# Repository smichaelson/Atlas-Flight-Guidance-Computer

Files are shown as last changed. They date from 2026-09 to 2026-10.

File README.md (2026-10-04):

# Atlas Flight Guidance Computer

Atlas is a collaborative STM32H743 flight-computer development project for the Rev. 0.1 board. It provides sensor and communications drivers, a statically allocated FreeRTOS framework, owned peripheral services, build projects, and reviewed hardware exports.

**Current status: diagnostic firmware 1.3.0; hardware qualification ongoing.** ServoBench now includes [four-servo gravity stabilization](docs/STABILIZATION.md) for a fixed bench demonstration, with a dashboard tab, SD-saved calibration/enable setting and SW2 control independent of USB. Read the [three-pass review](docs/STABILIZATION_REVIEW.md) for evidence and remaining physical checks. Manual single-servo workbench operation retains its direct moves, corrected PCB numbering, ADC averaging and 8.55 V cutoff. The rev-0.1 RGB and pyro inhibits remain mandatory. Passing builds and host models do not establish flight readiness.

## Start here

**Dashboard:** double-click **Start Atlas Dashboard.cmd** on Windows or [**Start Atlas Dashboard.command**](Start%20Atlas%20Dashboard.command) on macOS (Intel or Apple silicon). Install Python 3.10+ first; the launcher prepares its own environment and installs the bundled dashboard dependency offline. See the [Ground Station guide](docs/GROUND_STATION.md#start-the-dashboard) for setup, demo mode and Mac troubleshooting.

**USB updates and firmware builds:** see the [Ground Station guide](docs/GROUND_STATION.md). **Atlas Dashboard Demo.cmd**, **Build Atlas Firmware.cmd**, and **Build Atlas ServoBench.cmd** remain the Windows shortcuts. The latter builds the separate [manual servo profile](docs/SERVO_BENCH.md). Software DFU entry works after one initial installation. Firmware building/programming needs separate ST tools; they are not installed by the dashboard launcher. The [three-pass review](docs/GROUND_STATION_REVIEW.md) records the tested scope and physical checks still pending.

**PCB on the bench? Start with [startup](docs/startup.md)** — the complete power/BOOT0/reset/USB-programming procedure, local dashboard and staged tests. Build the **Bringup** preset, not the normal Debug/Release application. Check the documented USB schematic/manufacturing polarity conflict against the actual board before USB use.

For code collaboration, read [Quick start](docs/QUICK_START.md) and [Systems](docs/SYSTEMS.md): what runs, how to build/check it, and what remains unverified.

For implementation, use [Peripheral services](docs/PERIPHERALS.md) and [Development and engineering standards](docs/DEVELOPMENT.md). The [documentation hub](docs/README.md) indexes optional device, RTOS and hardware references. The [current review report](docs/REVIEW_REPORT.md) records corrections, three review passes, evidence and remaining release gates.

## Repository map

| Location | Purpose |
|---|---|
| [App](App/) | Drivers, RTOS ownership, typed snapshots, copied commands and safety policy |
| [Core](Core/), [FATFS](FATFS/), [USB_DEVICE](USB_DEVICE/) | Generated setup plus maintained board/filesystem/USB integration |
| [Tests](Tests/) | Protocol, integration, service-model and repository checks |
| [tools/bringup](tools/bringup/) | Offline-capable desktop dashboard, image verification and safe SD fixtures |
| [docs](docs/README.md) | Central documentation; references are optional, not a reading chain |
| [hardware](hardware/README.md) | Schematic PDF, BOM and candidate manufacturing exports |
| [ThirdParty](ThirdParty/), [Drivers](Drivers/), [Middlewares](Middlewares/) | Pinned dependencies; local USB patches are documented in provenance |
| [CMakeLists.txt](CMakeLists.txt), [EWARM](EWARM/) | Arm GNU and IAR project definitions |
| [Atlas.ioc](Atlas.ioc) | Generator inputs; runtime overrides and manual integrations must survive regeneration |

## Safety and provenance

All PWM, general GPIO and pyro outputs start disabled/low. The isolated **Bringup** image never enables PWM/pyro or calls the flight hook; it permits only explicit, one-second logic-GPIO tests and indicator/link/media actions. The separate **ServoBench** image permits one voltage-checked manual PWM channel with USB/time limits, or four explicitly configured stabilization channels gated by SW2 and sensor/power health. Stabilization can continue without USB; pyro remains inhibited. In the normal application, pyro arming and PWM operation require explicit qualified configuration; no flight decisions or remote firing parser are provided. The specified pyro policy is a 500 ms pulse, at least 500 ms OFF, and at most three retries: **four attempts per channel per boot**. Re-arming does not refill that budget.

Keep the physical pyro arm link open and disconnect energetic loads and servos during ordinary development. J5's armed feed bypasses the main eFuse. Use current-limited bench power; USB does not power the system rails. Output-low is an electrical state, not a guaranteed safe mechanical servo position.

No project-level license has been selected; vendor licenses remain applicable. See [provenance](docs/reference/PROVENANCE.md).

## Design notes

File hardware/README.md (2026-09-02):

# Hardware Reference Package

This directory contains review and manufacturing exports for the Atlas Flight Computer Rev. 0.1. It does not contain the editable KiCad project.

For contributor-facing pins, power and known discrepancies, use the centralized [hardware reference](../docs/reference/HARDWARE.md). For firmware capability and acceptance, use [Systems](../docs/SYSTEMS.md); this directory is the artifact manifest, not another bring-up guide.

## Files

- `Atlas-schematic-rev-0.1.pdf` - ten-page KiCad schematic PDF export, title-block date 2026-03-19.
- `AtlasBOM.csv` - generic component BOM from the source hardware folder.
- `manufacturing/` - candidate Gerber, drill, JLCPCB BOM, and component-placement package.

## Authority and limitations

The assembled board and confirmed as-built order records override these exports. The schematic is the primary electrical reference in this repository, while the firmware pin labels and `.ioc` configuration are implementation artifacts.

The exact files used for the already manufactured board were not identified in the source folder. Do not reorder from `manufacturing/` without completing the checks in [`manufacturing/README.md`](manufacturing/README.md).

No `.kicad_sch`, `.kicad_pcb`, `.kicad_pro`, footprint library, or symbol library is included. Obtain the canonical editable project from its owner before changing the design. Do not reconstruct an authoritative board from Gerbers.

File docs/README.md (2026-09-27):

# Atlas documentation

- [Four-servo bench stabilization](STABILIZATION.md) and [three-pass review](STABILIZATION_REVIEW.md).
- [Acknowledged RFD900x bench connection](RADIO_LINK.md) and [three-pass review](RADIO_LINK_REVIEW.md).
- [Remote Atlas sensor telemetry](REMOTE_TELEMETRY.md) and [three-pass review](REMOTE_TELEMETRY_REVIEW.md).

## Choose the question, not a reading list

| I need to… | Read |
|---|---|
| Power up the new PCB, program over USB and run the dashboard/tests | **[startup](startup.md)** — one complete bench procedure |
| Use the new browser dashboard and later USB updates | [Ground Station](GROUND_STATION.md), with [three-pass evidence](GROUND_STATION_REVIEW.md) |
| Test one free KST X10 servo with measured supply margin | [Servo bench workbench](SERVO_BENCH.md) |
| Understand the project and run its first checks | [Quick start](QUICK_START.md) |
| Know whether a subsystem is usable and how to accept it | [Systems and readiness](SYSTEMS.md) |
| Use SD, USB, ADC, GPIO, PWM, pyro, expansion or commissioning APIs | [Peripheral services](PERIPHERALS.md) |
| Build, test, add code, or review a change | [Development and engineering standards](DEVELOPMENT.md) |
| Understand a reported defect or the latest review evidence | [Current review report](REVIEW_REPORT.md) |
| Work on task ownership, timing, snapshots, or watchdogs | [RTOS reference](reference/RTOS.md) |
| Trace connectors, rails, pin assignments, or hardware conflicts | [Hardware reference](reference/HARDWARE.md) |
| Check vendor versions, licenses, or import decisions | [Provenance](reference/PROVENANCE.md) |

New collaborators normally need only **Quick start + Systems**. Bench operators use **startup** as their single procedure. References below are for the device or layer you are changing, not prerequisites to reading the application code.

## Device references

| Motion and environment | Navigation and links | Feedback |
|---|---|---|
| [ADXL375 high-g accelerometer](reference/modules/ADXL375.md) | [NEO-M9N GNSS / GPS](reference/modules/GNSS.md) | [RGB LED — hardware inhibited](reference/modules/LED.md) |
| [LSM6DSV16B IMU](reference/modules/LSM6DSV16B.md) | [NINA-B112 BLE](reference/modules/BLE.md) | [Differential buzzer](reference/modules/BUZZER.md) |
| [MMC5983MA magnetometer](reference/modules/MMC5983MA.md) | [RFD900x radio — J9 “LoRa” label](reference/modules/RFD900X.md) | |
| [MS5611 barometer](reference/modules/MS5611.md) | | |
| [BNO085 sensor hub](reference/modules/BNO085.md) | | |

SD, USB, ADC, PWM, GPIO, pyro and expansion now have owned services. Their commands, data units, result lifetime and qualification rules are centralized in [Peripheral services](PERIPHERALS.md). [Systems](SYSTEMS.md) distinguishes implementation from physical acceptance.

## How these documents stay authoritative

- **Systems** owns current capability and acceptance status. The **review report** owns current finding IDs and review evidence.
- **startup** owns the staged bench procedure, BOOT/reset/USB programming, dashboard use, fixtures and diagnostic wire protocol. Do not duplicate those procedures in device guides.
- **Development** owns engineering standards and build/test commands. **Peripheral services** owns the new board-service API contracts; **RTOS** owns scheduling and cross-owner rules. Per-device guides own protocol details.
- **Hardware** summarizes the schematic but never overrides as-built measurements, exact-part specifications, or unresolved discrepancies.
- [Earlier reviews](archive/REVIEW_HISTORY.md) are historical evidence only. Their “pass” conclusions and pre-correction failures do not supersede the current report.

This layout replaces the scattered status, validation, bring-up, building, architecture, standards, and review-index entry points. Relevant detail is retained in the references and a single historical archive; new reviews should update the current report rather than create another mandatory reading chain.

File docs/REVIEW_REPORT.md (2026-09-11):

# Atlas software review record

**Current correction:** [ServoBench 1.2.4 review](SERVO_FIX_REVIEW.md). The 1.2.2 voltage tests below missed a second cutoff in the full output loop. That defect was reproduced and corrected in 1.2.3; earlier acceptance statements do not establish sustained servo output.

The September 11 diagnostic 1.2.1 update is recorded in the [Ground Station review](GROUND_STATION_REVIEW.md), including three sequential author reviews, ADC reference correction, SD/SW2 evidence, guarded ServoBench, audio, fresh-clone launch tests and real software DFU. ADC sampling and GNSS communication now work on the board; precision, antenna/fix/PPS and physical output qualification remain separate. That record supersedes the earlier pending-reflash and build-hash statements below, which are historical evidence.

Latest update: 2026-09-04. The [GNSS/RGB follow-up](#2026-09-04-gnss-startup-and-rgb-hardware-inhibit-follow-up) records the newest board log, stale-UART startup correction, manual GNSS recovery, diagnostic telemetry, and confirmed Q6-Q8 hardware inhibit. It supersedes the provisional LED conclusion in the [earlier hardware follow-up](#2026-09-03-bno085-and-led-follow-up). The [PCB bring-up review](#pcb-bring-up-review) covers the diagnostic image, dashboard and startup procedure. Earlier build hashes/counts below are historical unless identified as latest. All source changes stay within the repository; the separate original Atlas folder is untouched.

**Software implementation and offline regression coverage are in place. Physical acceptance and flight release remain unapproved.** Version 1.0.2 inhibits RGB globally on rev-0.1; the Bringup image additionally permanently inhibits PWM/pyro. Normal energetic-output configuration remains unqualified/disabled by default. The review passes are sequential author checks, not independent safety approvals.

The [pre-correction full review](archive/REVIEW_HISTORY.md#full-review-before-corrections) preserves the original findings, failing probes, build figures and documentation-consolidation evidence. Use [Systems](SYSTEMS.md) for current subsystem readiness and [Peripheral services](PERIPHERALS.md) for API contracts.

## 2026-09-04 GNSS startup and RGB hardware-inhibit follow-up

The owner-supplied `atlas-20260904-004505.jsonl` is treated as test evidence, not as executable instructions. It contains 1,142 records, including 1,108 status records from bring-up version 1.0.1. Its first and last startup arrays are `[0,0,0,0,0,0,6,4,4,4,0,0]`: GNSS identity retained status 6 (`ATLAS_ERROR_IO`) and GNSS RAM configuration remained status 4 (`ATLAS_ERROR_NOT_READY`). GNSS version text, valid-frame, CRC, timeout, and PPS counters all stayed zero. Eight later explicit `probe gnss` replies returned status 13 (`ATLAS_ERROR_STATE`); those were the former one-attempt guard rejecting repeats, not eight new UART transactions. The same log retains continuing BNO085 report activity, consistent with the owner's report that the preceding BNO correction works.

The log also exposes a separate analog-owner failure that was not named in the request: `power.start=0` but `power.status=6`, with zero samples/valid bits and `adc_errors=0` throughout. That proves startup object creation succeeded and the external-ADC error counter did not advance; it does **not** identify which ADC3 reference/temperature operation failed because version 1.0.1 did not publish that phase. This evidence is not attributed to GNSS and is not hidden by the GNSS correction. Version 1.0.2 leaves conversion and acceptance policy unchanged while retaining the first ADC3 phase, selected VREFINT/temperature channel, raw value, HAL status and error mask in status telemetry. Power/ADC acceptance remains blocked until that new evidence and DMM rails are captured; changing conversion behavior speculatively would weaken the fail-closed output boundary.

Version 1.0.1 did not publish the failing GNSS phase or UART HAL state. The zero GNSS command-timeout count limits the original fault to work before or during the first MON-VER send; it does not prove a receiver/antenna failure. A specific startup race exists in the bundled STM32 HAL: NEO-M9N normally emits NMEA at 38400 baud before a staged probe, and `HAL_UARTEx_ReceiveToIdle_IT()` can return `HAL_ERROR` when an already-pending overrun aborts reception while it is being armed. The previous Atlas transport armed RX without first clearing stale hardware state. A timer/capture error before MON-VER also mapped to the same generic status, so the old log cannot distinguish those paths.

Version 1.0.2 corrects and exposes the boundary:

- UART start uses `HAL_UART_AbortReceive()` to disable stale receive state, clear hardware errors, flush RX, and restore READY before arming. One complete preflight/arm retry covers a receiver byte racing the short window; retries are bounded.
- GNSS sends only the read-only MON-VER identity poll every 250 ms inside one bounded 3 s startup window, so a command sent while the receiver protocol engine is still starting is not its sole opportunity to respond.
- GNSS proves checksum-valid MON-VER before it starts TIM2 channel-1 capture. A communication failure therefore leaves PPS unstarted and can be retried without clearing a live capture operation.
- A deliberate repeated GNSS probe first stops the failed transport. If identity had succeeded and only RAM configuration failed, it retries only configuration. Other modules and a fully successful GNSS remain single-shot.
- Health now retains stages 1–10, typed status, PPS-start state, RX/TX/drop/error/restart/preflight/retry counters, and HAL status/error. The dashboard renders them and the startup guide maps each stage to power/continuity/waveform checks.

The owner separately confirmed the actual LED design error from the raw KiCad source. DMN3404L Q6-Q8 are physically pin 1 gate, pin 2 source, pin 3 drain, while rev-0.1 routes intended load/control/ground to pads 1/2/3. Version 1.0.2 removes startup colors and dashboard on-controls, makes every nonzero direct/RTOS request unsupported, performs unconditional low writes, and requires `led_inhibited:true` plus zero-command status. The former “firmware mapping correct” conclusion is withdrawn.

### Three focused review passes

| Pass | Review performed | Result |
|---|---|---|
| 1 — evidence and hardware/driver contract | Parsed the complete new log; separated the single original I/O failure from rejected repeats; traced GNSS USART/PPS order, generated PB14/PB15/PA15 setup, U23 supply/SAFEBOOT/reset routing, bundled HAL receive-error behavior, official u-blox UART defaults, and official DMN3404L terminals | Failure is localized to a pre-MON-VER path but not falsely attributed from missing v1.0.1 telemetry; the real stale-RX race and confirmed Q6-Q8 mismatch have explicit dispositions |
| 2 — implementation and adverse paths | Added forced-low RGB tests, parser/UI/handshake denial, stale pre-probe UART injection, post-preflight arm-race injection, typed GNSS phases, a modeled 12-poll/3 s no-response bound, failed-identity/manual-retry coverage, shared-TIM2 regression coverage, and retained first-failure ADC3 telemetry tests | Host, service, bring-up and focused review suites pass; nonzero RGB requests cannot write high in the driver model; failed GNSS identity does not start PPS and a quiesced retry succeeds; ADC3 diagnostics do not alter conversion policy |
| 3 — target, documentation and final-diff review | Rebuilt both profiles/configurations, verified manifests/vectors/hashes, reran target diagnostics and all offline suites, checked documentation links/API tags, searched for LED-high paths, and reviewed the complete diff | See [latest executable evidence](#latest-executable-evidence). Physical GNSS communication and low-pin measurements remain required after flashing 1.0.2 |

These passes validate source behavior against controlled models. They do not prove that the assembled receiver has power, correct UART waveforms, a working antenna/fix, or valid PPS. Do not interpret manual retry as permission for an unbounded loop; preserve diagnostics and correct the physical cause first.

## 2026-09-03 BNO085 and LED follow-up

The first owner-supplied board log showed the other four sensor paths sampling while BNO identity returned `ATLAS_ERROR_IO`, its report setup remained `ATLAS_ERROR_NOT_READY`, and every BNO count/timestamp stayed zero. U12 SA0/H_MOSI is grounded, so firmware now uses seven-bit `0x4A` and passes left-shifted `0x94` to the STM32 HAL. The prior `0x4B`/`0x96` value contradicted the manufactured board contract.

The follow-up `atlas-20260903-230631.jsonl` still contains no accepted BNO report, despite the operator observing one transient value before or outside the retained status sequence. It shows a stronger shared-bus signature: MS5611 stopped after eight valid samples and then accumulated I/O errors immediately after the BNO probe, whereas the wrong-address run had left it sampling. Review found that the adapter performed the four-byte header and full read inside one callback while a payload-ready EXTI edge could remain latched as a new packet. The resulting no-data poll can clock-stretch BNO085 and strand I2C1. Version 1.0.1 now follows CEVA's separate header/next-interrupt/full-continuation state machine, uses transfer-length-aware bounds, and requires a genuinely new falling edge or confirmed H_INTN HIGH-to-LOW cycle before every subsequent read phase. A terminal BNO transfer failure holds U12 reset and restores I2C1 plus both generated filters before leaving the BNO disabled. The vendored product-ID operation also has a retained five-second timeout instead of its upstream unbounded wait.

At this earlier checkpoint, the D5 orientation evidence and package-pad measurements led to a provisional conclusion that the three low-side stages were routed correctly, so version 1.0.1 added PB6/PB7/PD14 readback. The subsequent raw-KiCad inspection established that conclusion was wrong: Q6-Q8's PCB pad functions do not match the fitted DMN3404L terminal assignment. The 2026-09-04 section supersedes this interpretation and disables all three outputs.

### Three focused follow-up reviews

| Pass | Review performed | Result |
|---|---|---|
| 1 — failure reconstruction and unit boundaries | Re-parsed both logs; mapped direct-sensor counter 3 to MS5611; traced shared I2C1, H_INTN ISR timing, CEVA SHTP assembly and reference I2C HAL; rechecked D5/Q6/Q7/Q8 and generated TIM4/GPIO ownership | Reproduced the stale-edge/no-data-read mechanism; separated LED package-pad measurements from MCU gate evidence |
| 2 — implementation and adverse cases | Added a virtual BNO that enforces header/held-LOW/idle/continuation/held-LOW/idle at the 1,024-byte CEVA maximum, wrong-extra-read detection, write/address bounds, injected terminal timeout and complete shared-bus restoration; added LED stuck-gate readback injection and actual C JSON/dashboard decoding | Host and bring-up suites pass; a full driver test uses actual CEVA SH-2/SHTP for reset, four product IDs and four feature writes; a separate silent-response test returns bounded `SH2_ERR_TIMEOUT` |
| 3 — target, operator and preservation review | Clean target builds, image manifest/vector/hash verification, all offline suites, target diagnostics, documentation/link checks and final diff review | See [latest executable evidence](#latest-executable-evidence); later board evidence confirms BNO streaming, while RGB illumination testing is withdrawn because of the hardware defect |

These are sequential author reviews, not independent hardware/safety reviews. Later owner evidence reports sustained BNO communication; calibration, timing, error-free soak, and shared-bus qualification remain open. RGB illumination is no longer an acceptance step on rev-0.1.

## PCB bring-up review

The operator's single procedure is **[startup](startup.md)**. The diagnostic scheduler is deliberately separate from the normal application: no control hook, actuator configuration, PWM enable or pyro arming/firing. ADC/input/USB services start immediately; sensor/link probes and SD mounting/testing require explicit commands. Component absence is visible without invoking the normal flight sensor-freshness reset loop. GPIO tests are bounded logic-only requests, not actuator tests.

### Three additional review passes

| Pass | Review performed | Result |
|---|---|---|
| 1 — hardware and functional contracts | Traced boot/power/USB/connectors against schematic and manufacturing pad attributes; reviewed staged ownership, output denial, command allowlist, measurement units and removable-media behavior | Complete. Recorded the USB polarity/protection conflict and provisional power gates; corrected result-backpressure and reconnect/identification handling |
| 2 — implementation and adverse cases | Built both profiles in Debug/Release, inspected symbols/memory, ran target compiler analysis and injected protocol, output and storage failures | Complete. Tests cover duplicate IDs, loss/overflow, old sessions, blocked/stale clients, GPIO expiry/disconnect, exclusive SD create/readback and failures; first diagnostic watchdog fault is retained |
| 3 — operator walkthrough and preservation | Read the complete startup path against code/pins; cross-checked exact payloads, artifacts and dashboard labels; reran final builds/tests/analysis and compared the preserved checkout | Complete. Corrected 23-byte SD / 19-byte link fixture descriptions, fixed signed numeric edge/null display handling, and made UI disconnect recover even if serial close fails |

These are three separate, sequential **author** reviews, not three independent reviewers. No actual PCB, COM port, DFU session, RF peer, motor or energetic load was accessed by that software-only review; the 2026-09-03 follow-up above uses owner-supplied log and inspection evidence. The synthetic dashboard and modeled serial lifecycle do not establish Windows-driver/electrical interoperability.

### Latest executable evidence

Toolchain: Arm GNU 14.3.1, CMake 3.26.4, MinGW Makefiles/GNU Make, host GCC 13.1.0, Windows PowerShell 5.1 / PowerShell 7 and Python 3.12.13/Tk. The extension's `cube-cmake` environment and Ninja were not used for the successful builds; [startup](startup.md#build-the-correct-image) includes the tested Makefiles fallback. No IAR build was performed.

| Check | Final result | Evidence boundary |
|---|---|---|
| Four clean target builds | Pass, no compiler warnings | Complete diagnostic and normal linked GNU images; matrix below |
| Strict target compiler/analyzer | Full 40-unit/profile pass on 2026-09-02; the eight current board/bring-up/protocol/GNSS/IO/LED/RTOS/UART units rerun in both profiles and pass on 2026-09-04 | Real Arm objects compiled with `-O0 -Wall -Wextra -Werror -Wshadow -Wformat=2 -Wdouble-promotion -fanalyzer`; not syntax-only |
| Existing host, focused-review and service suites | Pass | Includes real GNSS/SD/FatFs/USB paths and inert output policy/adapter models; no physical timing claim |
| [Bring-up suite](../Tests/bringup/run_bringup_tests.ps1) | Pass | Four C test executables, **14 Python tests**, actual C console JSON decoded by the desktop code, and a hidden 14-row Tk smoke test |
| Framing/formatting | Pass | 100,000 deterministic fuzz bytes, overflow/loss recovery, finite allowlist, signed boundaries/nonfinite values, escaped identities and bounded output |
| Desktop lifecycle and artifacts | Pass | Inert open-with-DTR-low ordering, no automatic TX/retry, partial-write uncertainty, failed-close recovery, stale/reset handling, SD fixture preservation and wrong-image/vector/hash rejection |
| Repository/documentation checks | Pass | Required files, local links/heading anchors, App Doxygen tags, static-memory/build membership and artifact policy; the checker uses explicit UTF-8 and a PowerShell-5.1-compatible relative-path implementation; see reproducible commands in startup |
| Linked profile boundary | Pass | Diagnostic entry present; normal scheduler/control hook absent; `AtlasRtos_OutputsPermitted()` returns zero; tested command boundary separately denies PWM/pyro/configuration |

The compiler audit suppresses only the intentional infinite-loop diagnostic in `main.c` and `stm32h7xx_it.c`, after inspection of their fatal inhibit paths, as in the preceding audit. No other analyzer warning is waived. Tests using inert register/serial/filesystem boundaries state those limits in their sources; they are not complete kernel/device simulations.

| Configuration | FLASH bytes | DTCM bytes | AXI DMA bytes |
|---|---:|---:|---:|
| Bringup / Debug | 210856 | 121912 | 64 |
| BringupRelease / Release | 110512 | 121816 | 64 |
| Normal Debug | 204556 | 89984 | 64 |
| Normal Release | 105524 | 89960 | 64 |

DTCM totals include the 16 KiB main-stack reservation. Diagnostic `_ebss` is `0x20019C38` in Debug and `0x20019BD8` in Release: only **8904 / 9000 bytes** remain before the MPU guard at `0x2001BF00`. This is not space available for unreviewed new buffers. Main stack remains `0x2001C000`–`0x20020000`; both 32-byte DMA blocks remain in AXI SRAM. Every image has one strong SVC/PendSV/SysTick/ADC/DMA1-stream-0/1/OTG-FS handler and no linked allocator/printf entry points. Stack-frame inspection and high-water telemetry do not replace full call-chain/FPU/interrupt and physical load testing.

Both diagnostic HEX/BIN/ELF manifests pass the actual offline verifier, including target/profile, hashes, initial SP/reset vectors, checksummed HEX and bank-1 boundaries. Exact final HEX SHA-256 values from this checkout:

```text
Bringup Debug   16c50f232972c21aff416392d11492748bec53b9c84f898855223e06bcde421f
Bringup Release bec2d82dfc9514cbe3b5d4006677d43cc0616a624e259b04050184db9fd8aeef
```

Build artifacts are retained only in ignored `build/` trees. Rebuild from your checkout, verify its generated manifest, and retain that image's evidence; source paths/compiler differences can alter the binary/hash. This is an accidental-wrong-image/corruption check, not signed firmware authentication.

### Physical gates and preservation

Two hardware findings remain explicit. First, the PDF's J2/U16 USB data connections conflict with the expected exported copper pad assignments; neither source proves the assembled board. Perform the [unpowered D+→PA12 / D−→PA11 check](startup.md#usb-data-polarity-is-a-required-as-built-check) and review U16's VBUS support-pin wiring before USB commissioning. Second, the owner-confirmed Q6-Q8 terminal mismatch makes the rev-0.1 RGB stage unusable; firmware inhibits it rather than concealing or compensating for it. No PCB/netlist/manufacturing file was changed. The eFuse input threshold, provisional current limits, crystal/boot options and actual rail/temperature/ripple behavior also require the explicit physical gates in startup.

No result here verifies sensor calibration/axes, SD-card durability, GNSS navigation/PPS quality, BLE SPS peer compatibility or RF range. The diagnostic image intentionally cannot qualify active PWM/pyro operation; their separate inert acceptance plan and approved normal configuration remain required. No software claim replaces disconnection of those loads.

The original bring-up preservation audit against the pre-bring-up ZIP retained all 374 existing repository files, with 348 byte-identical and 26 intentionally changed; 18 files were added. Vendor sources were byte-identical at that checkpoint. This follow-up intentionally changes only CEVA `sh2.c` in the vendor set to bound product-ID discovery; the exact patch and test are recorded in [Provenance](reference/PROVENANCE.md#local-integration-changes-2026-09-02-through-2026-09-04). All **19 manufacturing SHA-256 entries** still pass. No existing file was deleted, nothing was staged/committed, and the original Atlas folder was not touched. Generated Python caches and ignored build artifacts are excluded from source-file counts.

The complete pre-bring-up checkout, including existing dirty changes and `.git`, remains recoverable from the external `atlas_before_bringup_20260902.zip`, SHA-256:

```text
FD14CEBA8B3E6E94268320B3FEC8F04E563771AFC37873D765ADCF831EA843ED
```

The remaining sections record the **preceding correction review** and its original measurements; the latest build matrix above supersedes its build figures for the present checkout.

## Scope and method

Review covers all project-owned App implementations/headers and changed startup, clocks, MSP/IRQ/fault adapters, SD/FatFs, USB core/class/PCD, GNU/IAR membership/linker integration, tests and current documentation. Vendor review is limited to relevant integration paths and preserved provenance—not a line-by-line certification or current vulnerability audit of every dependency.

The schematic's ten pages were inspected in the preceding review, with additional focused power/output/ADC/connector cross-checks during correction. No board, module, card, RF peer or energetic load was exercised. No flashing, RF transmission, persistent module commissioning, filesystem formatting or physical firing was performed.

Owner-confirmed requirements: RFD900x on J9; KST X10 V8.0 servos; nominal 500 ms pyro pulse; ongoing continuity dependent on physical J5 connection; explicit software arming; at most three retries; at least 500 ms OFF. The implementation conservatively caps **four attempts per channel per boot**, preserving the budget across disarm/rearm and manual requests.

## Three correction-review passes

| Pass | Scope | Status |
|---|---|---|
| 1 — functional and fault contracts | Startup/shared time, SD lifecycle, USB control/retention, output timer/DMA/ADC/queues, commissioning and expansion; focused positive/adverse model tests | Complete; corrected additional implicit SD remount, short USB control/status lifetime, output-OFF queue fencing and ECC duplicate-count issues |
| 2 — separate rerun by the author | Clean Debug/Release, strict target compiler/analyzer, map/stack/handler inspection, full suite reruns; cross-check newly centralized API documentation | Complete; also corrected IAR stack placement, missing GNU guard exclusion and unintended libc allocation paths |
| 3 — delivery and preservation | New-collaborator walkthrough, examples/links/checker negative controls, regression review, exact target-drift/preservation and final target reruns | Complete; published sources match staging, unchanged files are byte-identical, and actual-checkout builds/tests/analysis pass |

All three passes are separate sequential author reviews, **not reviews by other people**. Two qualified independent safety reviewers and inert physical acceptance remain release prerequisites under [Development](DEVELOPMENT.md#change-and-release-checklist).

## Finding disposition

“Corrected in software” means the identified code/ownership defect is addressed and relevant tests pass; it does not close its physical acceptance gate.

| ID | Disposition |
|---|---|
| [R01](#r01-gnss-startup-restarts-an-already-running-timer) | Corrected: idempotent shared TIM2 start preserves counter/capture |
| [R02](#r02-rtos-waits-do-not-guarantee-minimum-device-delays) | Corrected: minimum elapsed waits with phase/overflow/context handling |
| [R03](#r03-sd-lazy-initialization-uses-an-unconfigured-handle) | Corrected: full SDMMC configuration and explicit optional-media lifecycle |
| [R04](#r04-sd-read-completion-can-be-erased) | Removed by design: synchronous polling port has no SD DMA completion race |
| [R05](#r05-sd-timeouts-do-not-establish-buffer-release) | Corrected: no retained SD DMA ownership; bounded polling/reset and media-generation invalidation |
| [R06](#r06-default-memory-is-not-sdmmc1-or-dma1-accessible) | Corrected: CPU-only SD/USB; private AXI ADC/pyro DMA blocks in both linkers, ECC seeding |
| [R07](#r07-usb-is-not-a-complete-or-started-cdc-service) | Implemented/corrected: VBUS owner, CDC controls, retained RX/TX, reset/timeout handling and FIFO allocation |
| [R08](#r08-gnss-parser-has-no-truncated-frame-age-limit) | Corrected: bounded UBX frame/interbyte age and transport-loss resynchronization |
| [R09](#r09-hardware-labels-and-power-protection-claims) | Superseded/corrected: raw-design evidence confirms Q6-Q8 terminal mismatch; RGB is firmware-inhibited pending hardware revision |
| [R10](#r10-deadline-checks-do-not-cover-release-lateness) | Corrected deadline coverage, priorities and fault gates; physical schedulability remains unverified |
| [R11](#r11-configured-peripherals-are-not-complete-services) | Added owned storage/RTC, USB, ADC/GPIO/PWM/pyro, expansion and commissioning APIs; qualified output profile and physical acceptance still required |
| [R12](#r12-bno085-address-disagrees-with-the-board-strap) | Corrected: SA0-low U12 now uses seven-bit `0x4A` / STM32 HAL `0x94`; post-reflash hardware proof remains required |

## R01: GNSS startup restarts an already-running timer

[AtlasTime_StartCounter](../App/Src/atlas_time.c) accepts only READY/stopped or BUSY/running states. BNO085 and GNSS both use it; a second client no longer calls HAL start again or resets the shared counter. A stopped BUSY handle still fails closed.

The real GNSS/UART probe models BNO's already-running timer, proves one HAL start, preserves the counter and proceeds to MON-VER/configuration. This is not a complete BNO/board startup simulation; actual BNO time, GNSS readback and PPS remain bench gates.

## R02: RTOS waits do not guarantee minimum device delays

[The helper](../App/Src/atlas_time.c) uses upward rounding plus one tick-phase allowance, overflow-safe chunks and explicit context rules. Pre-scheduler HAL waits are chunked; nonzero ISR/suspended-scheduler use asserts. The [timing tests](../Tests/review/test_timing.c) cover zero, maximum integer duration, earliest legal wake, pre-scheduler and context failures at modeled 100, 1000 and 2000 Hz.

At 1 kHz, the tested requested 3 ms wait has a modeled minimum of 3001 us, replacing the former 2001 us failure. This fixes the logical minimum-wait contract used by MS5611, MMC5983MA and BLE. Physical command timing and full-system 1 kHz scheduling still require measurement.

## R03: SD lazy initialization uses an unconfigured handle

[The BSP](../FATFS/Target/bsp_driver_sd.c) now prepares the complete SDMMC1 handle, initializes at one bit and negotiates four bits. Absent/failed media is optional, not a startup crash. [The storage owner](../App/Src/atlas_storage.c) owns mount/unmount/read/append and the [disk port](../FATFS/Target/sd_diskio.c) permits initialization only after explicit mount authorization.

## R04: SD read completion can be erased

The old callback/DMA read path is replaced by synchronous polling. There is no “launch then erase completion” flag. A private aligned sector buffer accommodates unaligned callers; no caller is retained asynchronously. The obsolete weak-callback host wrapper was retired, with its original preserved in the pre-correction backup.

## R05: SD timeouts do not establish buffer release

SD no longer uses IDMA. Errors reset/quiesce the controller, invalidate the mounted generation and reject old-session operations. Both mechanical detect edges count, including rapid remove/reinsert. The owner checks media before queued file work; disk status invalidates FatFs cached metadata and ST's disk-init cache. A file operation cannot silently remount a replacement card.

Transfer waits are 250 ms/sector and readiness waits 1000 ms with yielding; HAL internal commands/preemption can extend total wall time. A partial/failed append has an uncertain outcome and is never automatically retried.

[The real FatFs/BSP/disk RAM-volume test](../Tests/review/test_sd_integration.c) covers initialization, immediate polling completion, unaligned reads/writes, ranges, timeout/reset, ready waits, absence, replacement/removal, append preservation, cached-file rejection after replacement, and successful **explicit** remount. [The storage-owner test](../Tests/services/test_storage_owner.c) adds queue backpressure, removal-before-write, short append, failed sync and partial RTC updates.

## R06: Default memory is not SDMMC1 or DMA1 accessible

DTCM remains appropriate for CPU-owned data/stacks. SD uses CPU polling and USB PIO. ADC1 and TIM6's GPIO sequencer use two 32-byte private blocks in AXI SRAM `.atlas_dma`, explicitly placed by [GNU](../STM32H743XX_FLASH.ld) and [IAR](../EWARM/stm32h743xx_flash.icf). Complete 64-bit ECC words are initialized before subword DMA access.

[AtlasIo_Start](../App/Src/atlas_io.c) checks exact handles, buffer bounds, reviewed clocks, factory calibration and D-cache-off startup. Completion/abort must establish quiescence before reuse; failed buffers are quarantined. DMA1-to-GPIO D3 connectivity and memory/ECC assumptions were checked against the bundled HAL and [ST AN4891](https://www.st.com/resource/en/application_note/dm00306681.pdf)/[AN5342](https://www.st.com/resource/en/application_note/dm00623136-error-correction-code-ecc-management-for-internal-memories-protection-on-stm32h7-series-stmicroelectronics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). Actual DMA routing, cache policy, ECC behavior and pulse width remain inert bench requirements.

Pass 2 additionally found that IAR left CSTACK placement implicit despite the fixed MPU guard. It now explicitly places the 16 KiB main stack at 0x2001C000 and excludes guard/stack from ordinary data. GNU asserts the same stack base and rejects data reaching 0x2001BF00. A link-only negative control exceeds the guard boundary while still fitting ordinary DTCM capacity; it correctly fails the new guard assertion.

The generated C-library allocator also ignored the zero-heap reservation and could grow toward that guard. [The replacement boundary](../Core/Src/sysmem.c) rejects all heap changes with ENOMEM; [its host test](../Tests/services/test_sysmem.c) covers zero, positive, negative and extreme requests. Radio/BLE AT formatting now uses bounded integer/string construction, with shortest/longest name and zero/maximum integer wire checks. No allocator/printf path remains linked in the current GNU images.

## R07: USB is not a complete or started CDC service

[AtlasUsb](../App/Src/atlas_usb.c) provides VBUS debounce/recheck, prompt disconnect and task-owned teardown, a 1024-byte RX ring and four copied TX packets. Sessions invalidate stale data; a 2000 ms TX timeout tears down without replay. The CDC adapter validates line coding/control requests, retains TX memory until final data/ZLP completion and safely rejects pre-enumeration access.

Review also corrected malformed direction/interface/size handling, short control OUT payloads, failure-to-stall/incorrect status ACKs, stack-lifetime EP0 data, two-byte endpoint status, rejected TX launch and missing EP2 TX FIFO. The explicit local middleware changes are recorded in [Provenance](reference/PROVENANCE.md#local-integration-changes-2026-09-02-through-2026-09-04).

[The CDC test](../Tests/services/test_usb_cdc.c) compiles the real adapter plus ST core/class. [The owner test](../Tests/services/test_usb_owner.c) scripts initialization-time VBUS loss, unplug, overflow, result lifetime, timeout and re-enumeration without replay. Neither emulates electrical USB or substitutes for actual host/OS enumeration. There is a byte service, not a supplied console or trusted command protocol.

## R08: GNSS parser has no truncated-frame age limit

[The parser](../App/Src/atlas_gnss.c) rejects payload lengths above its 512-byte bound immediately, enforces 250 ms interbyte and 2000 ms whole-frame limits, and flushes/reset-resynchronizes after transport overflow/restart. Age is observed at service time; UART bytes do not carry individual wire timestamps.

Tests include clean/fragmented NAV-PVT, embedded sync bytes, invalid checksum, truncated in-range/oversized frames, elapsed-frame limit, clock wrap and transport loss. A valid packet after the formerly blocking header is parsed; discarded-length state is zero.

## R09: Hardware labels and power-protection claims

The owner confirmed RFD900x at the “LoRa” J9 connector. Documentation explicitly identifies J5's feed from VIN_RAW to PYRO_VBAT_ARMED as **bypassing TPS16850 U11**.

The D5 orientation can be correct while its three low-side stages are not. The owner's later raw-KiCad inspection confirmed that rev-0.1 routes intended LED load, MCU control, and ground to Q6-Q8 pads 1, 2, and 3, whereas the fitted DMN3404L uses those physical pins as gate, source, and drain. The earlier “active-high mapping is correct” conclusion is withdrawn. All three outputs are now forced low and nonzero commands are unsupported; no schematic or manufacturing output was altered to hide the defect.

## R10: Deadline checks do not cover release lateness

Control now outranks blocking sensor/link work. Scheduled release—not actual wake time—starts the 10 ms response budget, including snapshot wait and hook. Late work inhibits outputs, latches a fault and skips catch-up bursts. Non-maintenance sensor cycles at least 20 ms also fault. Slow conversions/commands/expansion do not stack in one cycle, and stream UART waits are capped at 10 ms.

A lock-free output gate expires at the earliest required sensor age; the output owner additionally requires fresh calibrated ADC and valid rails. Maintenance rejects armed/active outputs, serializes the hold against enable, and keeps control/actuation inhibited during the bounded operation and recovery.

Pure deadline/supervisor tests pass. No full-kernel scheduling simulation or physical WCET/jitter/stack-load evidence exists; those remain mandatory.

## R11: Configured peripherals are not complete services

Added services and their [central contracts](PERIPHERALS.md):

- Static SD/UTC owner with explicit removable-media lifecycle and append/read results.
- VBUS-aware USB byte transport and validated CDC adapter.
- Calibrated asynchronous ADC, raw inputs, allowed-mask GPIO and KST PWM service.
- Hardware-independent pyro policy plus separate timer/DMA adapter, continuous qualified continuity, software/physical-supply gates, four-attempt per-channel/boot cap and conservative OFF guard.
- Sole-owner raw UART4/I2C2/SPI3 expansion work.
- Queued radio identity/settings/parameter/host-baud and BLE SPS commissioning; no automatic persistence.

Safety review found and corrected OFF-command generation fencing and ECC duplicate-event accounting. The first ECC monitor/offset/type is retained; HAL's accumulated event code is consumed only after evidence capture.

The stock image does not claim qualified servo neutral/travel, pyro voltage/continuity thresholds, successful deployment, RF peer service, navigation suitability, application framing/authentication or flight algorithms. These are explicit remaining configuration/qualification work, not hidden automatic defaults.

## R12: BNO085 address disagrees with the board strap

The owner-supplied 2026-09-03 bring-up log recorded BNO identity as `ATLAS_ERROR_IO`, left all four report enables `ATLAS_ERROR_NOT_READY`, and contained no BNO samples. Other I2C1 traffic reached the MS5611, so the log did not support treating the shared bus as generally dead.

Manufacturing net attributes connect U12 pin 17, `SA0/H_MOSI`, to ground. The BNO085 data sheet selects seven-bit address `0x4A` when SA0 is low, but the driver used `0x4B` and therefore passed `0x96` to the STM32 HAL. The driver and current documentation now use `0x4A`, which becomes HAL value `0x94` after the required left shift.

The corrected-address follow-up still failed and also stopped the shared-bus MS5611 after eight samples. The two-phase read, edge-rearmed readiness gate, length-aware timeouts, bounded product-ID operation, reset-first shared-bus recovery and `bno.health` telemetry described above are now implemented and regression-tested. After reflashing, retain the ticketed `probe bno` reply, health object, product IDs, all four successful feature-report enables, advancing report counts/timestamps, continuing MS5611 samples, and a joint H_INTN/I2C logic-analyzer trace if the probe still fails.

## Executable evidence

The review uses Arm GNU 14.3.1 (Arm build 14.174), CMake 3.26.4, MinGW Makefiles/GNU Make, host GCC 13.1.0 and PowerShell 7. No IAR compiler or physical board is available.

| Check | Delivered-checkout result | Boundary |
|---|---|---|
| Fresh GNU Debug and Release builds | Pass; zero compiler warnings in both | Complete linked firmware; figures below |
| Strict target compile/static analysis | Pass on 37 translation units | 23 App files, 10 project adapters and 4 USB middleware files; `-O0 -Wall -Wextra -Werror -fanalyzer` |
| Host protocol suite | Pass | 15 test groups, including added BLE name and radio integer-format boundaries |
| Focused review probes | Pass, exit 0 | Real timing/GNSS/SD/FatFs and pure analog/pyro logic with injected boundaries |
| Service suite | Pass, exit 0 | Real output/USB/storage/expansion owners, real USB core/class and rejecting C-library heap boundary |
| Repository checker | Pass; 309 local links and 61 linked heading anchors | Doxygen, build membership, artifact/static-memory/stack contracts |
| Documentation examples and API references | Four C blocks compile against target headers; 136 named API references resolve | Three peripheral examples plus the application hook; not physical execution |
| Preservation | Pass | 276 untouched files byte-identical; 98 changed/new text files match reviewed staging; one backed-up wrapper retired |
| Physical/IAR acceptance | Not performed | No electrical, RF, flight, complete-kernel simulation or IAR-binary claim |

The analyzer initially reported the deliberate terminal loops in `Error_Handler` and the fatal exception handlers. Their preceding emergency-inhibit paths were inspected. Only `-Wanalyzer-infinite-loop` is disabled for `main.c` and `stm32h7xx_it.c` in this audit; all other diagnostics remain errors. Formatting scratch buffers are initialized, and the final audit has no unexplained diagnostics. The audit does not prove all paths correct.

Run the commands in [Quick start](QUICK_START.md#2-run-the-complementary-checks), including the added bring-up suite. The old expected-failure baseline is archived; every current behavioral assertion must pass. Do not weaken a fixture just to obtain green output.

### Delivered GNU build evidence

These fresh builds use the actual Desktop repository, not merely the staging copy. Build products and logs are retained outside the repository.

| Configuration | FLASH bytes | DTCM bytes | AXI DMA bytes |
|---|---:|---:|---:|
| Debug | 201616 | 89792 | 64 |
| Release | 104008 | 89768 | 64 |

DTCM figures include the linker's main-stack reservation. The main stack starts at 0x2001C000, ends at 0x20020000 and has its guard at 0x2001BF00. The two private DMA blocks are each 32-byte-aligned in the 64-byte AXI NOLOAD section starting at 0x24000000; their internal order differs between configurations and is not assumed by the code. Release disassembly confirms full-width `STRD` ECC-seeding stores.

Both images contain exactly one strong SVC, PendSV, SysTick, ADC, DMA1 stream 0/1 and OTG_FS handler. No libc allocator, heap-growth, printf or FreeRTOS allocator entry point is linked. A separate positive/negative link control proves the GNU guard assertion rejects a data allocation that still fits ordinary DTCM capacity but enters the guard.

The largest observed individual Debug stack frames are 1104 bytes for the storage task, 888 for the supervisor and 640 for the application task. These are **not** complete call-chain, FPU, interrupt, or runtime stack-margin proofs.

SHA-256 of these exact local build artifacts:

```text
Debug ELF   2C93712CD73EA007A37371ED92C130D8D4647A7BDF6C719D127227148513E0E0
Debug map   BAE5F3EE6C747E6468ED4E6D23E8A3AE81E5A355C43CDA6907012C57027258CC
Release ELF 341B9D2926FBE2EDC95A58CC802D85D4AE2A29C90ED33774486525DDE3A66EAB
Release map 3BE8DD9080875729621BED196FC54B744AA1E9715CADF2D08CC53B060C7E8721
```

Compiler diagnostics/debug metadata include source locations; relocating the source tree can change hashes and diagnostic-string footprint. Reproduce with the recorded toolchain and compare executable behavior/configuration, not an unrelated machine's hash alone.

### Documentation and delivery controls

The repository checker passed positive controls for compact Doxygen blocks, pointer-return functions, duplicate heading suffixes and ignored fenced examples. Seven negative controls were then correctly rejected: a missing visible file, missing heading anchor, missing parameter tag, missing pointer-return tag, new kernel FromISR call, libc formatted I/O, and an inconsistent IAR stack base. Restoring those controls returned the checker to a pass. Control fixtures were isolated outside the delivered repository.

The current navigation has two entry documents (Quick start and Systems), with one central peripheral guide and one engineering-standards guide. Device details remain optional references; the archive is explicitly historical. A fresh-reader pass checked startup versus runtime behavior, units/channel numbering, queue acceptance versus execution, persistence, failure handling, and qualification prerequisites.

Before publication, all 343 existing repository files matched the preserved snapshot: no concurrent target edits were overwritten. The correction changed 66 files, added 32 and retired only `Tests/review/sd_bsp_host.c`, leaving 374 delivered files excluding Git internals. All 276 files outside that change set remain byte-identical. All 19 manufacturing-manifest hashes pass. Changed/new text was compared with reviewed staging after newline normalization; raw hardware exports were not normalized or changed. `git diff --check` passes.

The pre-correction snapshot, including the retired wrapper, remains in the external backup `atlas_before_fixes_20260901.zip`, SHA-256:

```text
88513F2E979303E0A7E8C59A9C2581F23D2304B97360AC5EA41EAD2AC67FAB3A
```

Existing checkout changes were retained. No files were staged or committed, no branch was changed, and the separate original Atlas folder was not modified.

## Remaining release gates

1. Exact board/load electrical qualification, measured servo neutral/travel, arm-voltage/continuity thresholds, supply tolerances and inert timer/DMA cutoff evidence.
2. Actual sensor/GNSS/SD/USB/BLE/RFD900x communications and failure/recovery tests, including navigation quality and peer operation.
3. Measured scheduling, memory, ISR and stack margins under worst-case combined traffic and fault conditions; actual IAR build if used.
4. Approved Q6-Q8 PCB correction/rework and separate LED requalification; BNO085 long-run/calibration/shared-bus evidence; authorized USB product identity; application logging/framing/security and approved flight-state logic.
5. Qualified independent safety review and a responsible-owner release decision. Three author passes and green host tests do not satisfy that release approval.

No physical firing, actuator activation, RF transmission, board flashing, module nonvolatile configuration or original Atlas-folder edits were performed.

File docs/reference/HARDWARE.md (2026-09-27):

# Rev. 0.1 hardware reference

This guide summarizes the [ten-page schematic export](../../hardware/Atlas-schematic-rev-0.1.pdf) and the compiled [pin definitions](../../Core/Inc/main.h)/[MSP setup](../../Core/Src/stm32h7xx_hal_msp.c). It is not an as-built inspection, electrical certification or fabrication approval. Runtime capability and acceptance live in [Systems](../SYSTEMS.md).

## Authority and limits

The board uses STM32H743ZIT6 (2 MiB flash). The schematic title block is Rev. 0.1, dated 2026-03-19. Confirm the assembled revision and exact fitted parts before relying on a mapping. Device data-sheet axes are not automatically the board/body frame.

Current source assumes an 8 MHz HSE, 200 MHz CPU, 100 MHz HCLK, 50 MHz APB buses and 100 MHz timer kernels for the used timer configuration. PLL2 provides the 50 MHz SPI/USART/SDMMC/ADC kernel selections; PLL3 provides 16 MHz I2C and 48 MHz USB selections. These are source-derived nominal values, not measured clock accuracy.

Raw KiCad projects are intentionally absent. Obtain the canonical editable design from its owner for hardware changes. [Hardware package](../../hardware/README.md) and [candidate manufacturing manifest](../../hardware/manufacturing/README.md) retain their separate provenance.

## Power and physical inhibit

| Path | Intended role |
|---|---|
| J1 → `VIN_RAW` | Main power entry; polarity must be checked |
| `VIN_RAW` → U11 TPS16850 → `VIN_PROT` | Main protected input feeding regulators |
| `VIN_PROT` → MP8772 → `8V4_PWM` | Shared nominal 8.4 V actuator-header power |
| `VIN_PROT` → LM76003 → `5V_SYS` | Radio/header and other 5 V loads |
| `VIN_PROT` → LM76002 → `3V3_SYS` | MCU digital and 3.3 V loads |
| Ferrite-filtered `3V3_AUX` | Analog, GNSS/BLE and low-noise branch |
| **`VIN_RAW` → physical J5 arm link → `PYRO_VBAT_ARMED`** | **Bypasses U11; the main eFuse does not protect this pyro feed** |

The prior hardware overview's “shared input protection” claim for pyro current was incorrect and is withdrawn. No independent per-channel fuse/current limiter is shown in those paths. Keep J5 open and energetic loads disconnected during ordinary work.

The schematic states a 16.3 V maximum input and an undercharged four-cell source. Treat that as the present boundary until the owner supplies an approved input specification; a fully charged nominal 4S pack can exceed it. An overvoltage fault cutoff is not an operating allowance. No separate reverse-polarity stage is shown ahead of `VIN_RAW`; use current-limited bench power and confirm polarity.

J9 is directly on `5V_SYS`, not behind an accessory TPS2553 limiter. Budget radio transmit peaks and power integrity using the exact modem specification. Two 5 V and two 3.3 V accessory ports have TPS2553 limiters, but their enables are tied high and fault outputs are not monitored by this firmware. They are not software power cutoffs.

PWM headers share a live power rail with no individual electronic limiter per channel. Stopped PWM does not mean an unpowered actuator connector. USB VBUS is sensed, not used to supply the system rails.

The populated R32=133 kΩ / R33=13.7 kΩ divider with a typical 1.21 V TPS1685x UVLO threshold implies approximately 12.96 V rising input enable. A 12 V supply may therefore not start the board. Verify as-built values and limits; the staged 15 V current-limited procedure and meter points are in [startup](../startup.md#3-first-power--no-usb-no-card-no-external-loads), not an approved battery/load envelope.

## Boot and USB as-built gates

STM32 BOOT0 is TP8/U6 pin 138 (10 kΩ pull-down); NRST is TP13/U6 pin 25 (10 kΩ pull-up and capacitor). TP12 is **GNSS** SAFEBOOT, not STM32 BOOT0. J28 is a custom connector, not a standard Cortex-debug pinout. The complete [programming/pin procedure](../startup.md#2-unpowered-inspection-and-pin-map) includes the required ground/reference connections and power sequence.

**Newly identified discrepancy:** PDF page 5 connects J2's drawn D− side to the net named USB_D+ and D+ side to USB_D−. Manufacturing copper pad attributes instead identify J2 A6/B6 → U16 I/O1 → PA12 D+, and A7/B7 → U16 I/O2 → PA11 D−, the expected polarity. Attributes are not a continuity test or a certification of actual copper/assembly. Require the [unpowered USB continuity check](../startup.md#usb-data-polarity-is-a-required-as-built-check) before USB bring-up. Resolve any reversal in hardware; the USB PHY cannot swap pins in firmware. U16's unconnected-looking VBUS support pin also needs protection-circuit review. No hardware exports were changed to conceal either discrepancy.

## Sensor and communications connections

Addresses below are seven-bit I2C addresses; the HAL adapter applies the required address shift.

| Device/interface | MCU connection | Source-defined baseline |
|---|---|---|
| SPI2 bus | PB10 SCK, PC2_C MISO, PC3_C MOSI | Mode 3, prescaler 16, nominal 3.125 MHz; inspect actual signal integrity |
| ADXL375 U1 | SPI2; CS PG12; board MOSI gating | 400 Hz, 4-wire/right-justified |
| MMC5983MA U9 | SPI2; CS PG11 | On-demand conversion, 200 Hz bandwidth code |
| SPI3 bus / LSM6DSV16B U27 | PB3 SCK, PB4 MISO, PB2 MOSI; IMU CS PG10, INT1 PG2 | Mode 3, nominal 3.125 MHz; INT2 at TP11 |
| I2C1 bus | PB8 SCL, PB9 SDA | Shared BNO085/MS5611; external pull-ups |
| BNO085 U12 | I2C1 `0x4A`; reset PB13, active-low interrupt PG0 | SA0/H_MOSI is strapped low; four SH-2 reports; shares TIM2 timebase with GNSS |
| MS5611 U14 | I2C1 `0x77` | PROM/CRC, compensated D2/D1 conversion |
| NEO-M9N U23 | USART1 MCU TX PB14 / RX PB15; PPS PA15 TIM2 CH1 | 38400 8N1 host; stale-RX preflight before `MON-VER`; intended RAM-only 10 Hz NAV-PVT; external antenna J27; reset not MCU-routed |
| NINA-B112 U21 | USART6 MCU TX PG14 / RX PG9, RTS PG8 / CTS PG15 | 115200 8N1 RTS/CTS; reset PD4, SWITCH1 PG5, SWITCH2 PG4, module DSR driven PG6, DTR observed PE1 |
| RFD900x J9 | USART3 MCU TX PD8 / RX PB11; 5 V and ground | 57600 8N1 host; no routed radio hardware flow control |
| microSD | SDMMC1 D0–D3 PC8–PC11, CK PC12, CMD PD2; detect PD3 | One-bit initialization then four-bit / 25 MHz polling; PD3 active-low mechanical J3 detect |
| USB full-speed device | PA11 D−, PA12 D+; divider-sensed VBUS PA9 | VBUS-gated CDC owner; PIO, no USB DMA |
| External UART | UART4 MCU RX PD0 / TX PD1 | 115200 8N1 initially; explicit raw expansion service |
| External I2C | I2C2 SDA PF0 / SCL PF1 | Raw/register transaction service; attached-device contract required |
| External SPI | Shared SPI3; external CS **PG13** | Raw transaction service; mode 3 / nominal 3.125 MHz, serialized with the IMU |

J9's **RFD900x** assignment was explicitly confirmed by the owner on 2026-09-01. The schematic and generated `LORA_*` labels are legacy names. RFD900x uses its serial-modem/SiK interface, not a Semtech LoRa register protocol.

## Outputs and monitoring

| Group | Mapping / limitation |
|---|---|
| PWM1–4 | TIM1 CH1–4: PE9, PE11, PE13, PE14 |
| PWM5–8 | TIM3 CH1–4: PC6, PC7, PB0, PB1 |
| PWM setup | Runtime prescaler 99, period 3002: 1 MHz / 333.0003 Hz; disabled/GPIO-low until qualified enable |
| GPIO outputs 1–7 | PF2, PE4, PA5, PA7, PC5, PF14, PF13; initialized low |
| GPIO inputs 1–7 | PE2, PE3, PG1, PE7, PE8, PE10, PE15; raw input snapshot; application polarity/debounce/semantics remain explicit |
| External switch | PF12 raw input snapshot; no automatic arming/flight meaning |
| Pyro gates 1–5 | PD9–PD13; disarmed/low; qualified TIM6 + DMA1 Stream1 two-edge pulse service |
| Buzzer | PE5 TIM15 CH1 / PE6 CH2; runtime PWM1/PWM2 opposite phase; stopped initially |

TIM15's nominal 4.8 kHz request rounds to 208 counter counts (about 4807.7 Hz). Measure both terminals and their differential voltage. A scheduled beep stops only when I/O service reaches its expiry check.

| Analog source | ADC1 sequence / pin | Nominal conversion aid—not a threshold |
|---|---|---|
| `3V3_SYS` | Rank 1 / IN16 / PA0 | Divider ×2 |
| `8V4_PWM` | Rank 2 / IN10 / PC0 | Divider approximately ×3.105 |
| `5V_SYS` | Rank 3 / IN11 / PC1 | Divider ×2 |
| `VIN_PROT` | Rank 4 / IN2 / PF11 | Divider approximately ×9.133 |
| Armed bus | Rank 5 / IN17 / PA1 | 820 kΩ / 100 kΩ divider |
| Continuity 1–5 | Ranks 6–10 / PA2, PA3, PA4, PA6, PC4 | 470 kΩ feed, 100 kΩ return, 10 nF filtering |

The output owner calibrates both ADCs. ADC1 uses a completed-only ten-rank scan in AXI SRAM; ADC3 uses separate single-rank VREFINT and temperature conversions. Runtime overrides the generator's original ADC3 sequencing. The snapshot and bring-up status retain the first ADC3 operation/channel/raw/HAL failure independently from the external ADC1/DMA error count. Those diagnostics localize a software/hardware boundary but do not qualify reference accuracy. Divider ratios, reference/offset, settling, tolerances and safe diagnostic current require assembled-board validation. Do not derive firing permission from nominal divider arithmetic.

J5 has no independent digital contact sensor. The qualified armed-feed voltage is a supply-present proxy, not proof that a safe arm link/load is fitted. Continuity is UNKNOWN without that supply and during firing. The ADC equivalent drain multiplier is 5.7; the armed-supply multiplier is 9.2. Thresholds are application-supplied only after measurement; no qualified defaults exist.

## RGB LED hardware defect and mandatory inhibit

The board owner confirmed the D5 orientation, then identified the controlling defect in the raw KiCad design on 2026-09-04. The fitted Q6/Q7/Q8 type is DMN3404L-7, whose SOT-23 terminals are pin 1 gate, pin 2 source, and pin 3 drain. The PCB routing instead sends the intended LED load to transistor pad 1, MCU control through 220 Ω to pad 2, and ground to pad 3. Thus all three intended low-side stages have gate/source/drain assigned to the wrong physical terminals. D5 orientation or a software color swap cannot correct this.

| Legacy control / intended channel | Affected transistor path | Rev-0.1 result |
|---|---|---|
| PB6 `LED_R` / red | R106 → Q8 → R105/D5 | MCU drives pad 2/physical source; load reaches pad 1/physical gate; pad 3/physical drain is grounded |
| PB7 `LED_G` / green | R102 → Q7 → R101/D5 | Same terminal mismatch |
| PD14 `LED_B` / blue | R104 → Q6 → R103/D5 | Same terminal mismatch |
| `5V_SYS` / common anode | D5 supply | A correct anode supply does not repair the invalid switches |

Version 1.0.2 permanently treats PB6/PB7/PD14 as fail-dark outputs on this revision: initialization writes and verifies low, board startup has no color indications, nonzero requests are unsupported, and the updated dashboard requires explicit LED-inhibit telemetry. Do not drive these nets high or perform further illumination tests until approved hardware rework/a corrected PCB revision is electrically inspected and qualified. See the dedicated [RGB LED guide](modules/LED.md).

## Verification boundary

All schematic pages were visually checked for this review, including USB and the output/power paths. That did not validate PCB routing, manufacturing alignment, component substitutions, assembled wiring or electrical margins. [Systems acceptance gates](../SYSTEMS.md#acceptance-gates) and the [review report](../REVIEW_REPORT.md) retain those limitations.

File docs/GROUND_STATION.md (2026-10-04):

# Atlas Ground Station and USB updates

ServoBench **1.3.0** adds an autonomous [Stabilization tab](STABILIZATION.md): four radial servos, SD-saved settings and physical SW2 control. The single-channel USB/time limits below describe manual Servo workbench operation; stabilization has separate sensor, power and switch limits. See the [three-pass review](STABILIZATION_REVIEW.md).

Version 1.2.6 adds **Happy Birthday** beside Imperial March in Test controls. It plays once for 12 seconds, with the same Stop control and live playback status. Both diagnostic firmware profiles support it; older firmware keeps the new button disabled. See the [three-pass melody review](BIRTHDAY_REVIEW.md).

Version 1.2.5 applies each selected servo angle directly, using the servo’s own position controller. The dashboard offers angle buttons and numeric entry across nominal ±50°. It retains the corrected PCB PWM numbering (right 1 to left 8), 16-sample ADC averaging and 8.55 V output-loop cutoff. See the [servo review](SERVO_FIX_REVIEW.md). Version 1.2.2 added the owner-selected 8.55 V ServoBench cutoff and repairs the march transition. It retains the 1.2.1 work that corrects the ADC reference scaling, exposes SW2 and SD diagnostics, adds startup audio, and provides a separate ServoBench image for manual KST X10 tests. Atlas uses battery power; USB-C carries data. Follow the board inspection and power requirements in [startup](startup.md), including the 16.3 V input limit and mandatory RGB inhibit. Keep J5 open and pyro loads disconnected. Servos stay disconnected until the [servo bench procedure](SERVO_BENCH.md) is satisfied.

## Start the dashboard

Double-click **Start Atlas Dashboard.cmd** on Windows or [**Start Atlas Dashboard.command**](../Start%20Atlas%20Dashboard.command) on macOS, inside the complete repository folder. Both open [Atlas Ground Station](http://127.0.0.1:8765) in your default browser. Keep the launcher window running. **Atlas Dashboard Demo.cmd** opens explicitly simulated instruments and servo models with hardware actions disabled; the Mac launcher accepts `--demo` or you can choose **Explore demo** in the dashboard.

On a fresh Windows laptop, install Python 3.10 or newer with its Python launcher first. The Atlas launcher creates this clone's `.venv` and installs the bundled, SHA-256-verified pyserial wheel without network access. Do not copy another computer's `.venv`, browser shortcut, or absolute path. No Node packages, accounts, map service, or compiler are required for the dashboard. A failed setup leaves the error visible and details in `.atlas-launch.log`; an unusable environment is preserved under a timestamped name.

### macOS setup

1. Install a current Python 3 release (minimum 3.10) using the [official macOS installer](https://www.python.org/downloads/macos/). Its universal installer supports Intel and Apple silicon. Existing Homebrew Python installations also work; Homebrew is not required. Apple's `/usr/bin/python3` development-tools installation is deliberately skipped. See [Python's macOS guide](https://docs.python.org/3/using/mac.html).
2. Extract or clone the complete repository into a writable folder, then double-click **Start Atlas Dashboard.command**. It finds Python even with Finder's limited search path, creates `.venv/bin/python`, verifies and installs bundled pyserial 3.5, and launches the same dashboard as Windows. Python itself is a one-time prerequisite; Atlas's dependency setup needs no internet connection or administrator access. Tk is not required by this browser dashboard.
3. Keep Terminal open while using Atlas; press **Control-C** to stop the server. If the browser does not open, use the local address printed in Terminal. Select Atlas's `/dev/cu.usbmodem...` USB device in the dashboard; the exact suffix varies.

If a ZIP/extraction tool loses the executable permission, open Terminal in the repository folder and run:

```sh
chmod +x "Start Atlas Dashboard.command"
./"Start Atlas Dashboard.command"
```

From that folder, these optional commands check setup, start a demo, or choose another port:

```sh
/bin/bash "Start Atlas Dashboard.command" --check
/bin/bash "Start Atlas Dashboard.command" --demo
/bin/bash "Start Atlas Dashboard.command" --port 8766
```

`--check` prepares and verifies dependencies and prints the launch command; it does not open a server, browser, serial port or firmware operation. `--no-browser` starts the server and leaves browser opening to you. For a custom Python location, set `ATLAS_PYTHON` to its full executable path. Setup errors remain visible in Terminal; Python bootstrap errors also write `.atlas-launch.log` in the repository. An unusable environment is preserved and replaced; missing pip is repaired offline.

This launcher is for **macOS computers**, not iPhone/iPad. Firmware builds and USB DFU programming need their own tool installation and remain outside the Mac launcher verification. Native Finder/browser behavior and a physical Mac-to-Atlas USB connection have not been tested locally. See the [Mac launcher review](MACOS_LAUNCHER_REVIEW.md) for performed checks and the Mac CI coverage.

### Windows options and existing sessions

Launch paths are resolved from the launcher and Python source, regardless of the working directory. Repository documentation links are relative. `127.0.0.1` always refers to the computer running that copy of the dashboard; it does not connect to another laptop's server.

If the same clone already owns the port, the launcher opens its existing session. A different clone or older server on that port produces a clear message; close its launcher or run:

```powershell
& '.\Start Atlas Dashboard.cmd' --port 8766
```

For a setup/path check that does not open a server, browser, serial port or firmware operation:

```powershell
& '.\Start Atlas Dashboard.cmd' --check
& '.\Atlas Dashboard Demo.cmd' --check
```

The original [Tk dashboard](../tools/bringup/dashboard.py) remains available for ordinary Bringup diagnostics; the browser dashboard owns the ServoBench workflow.

## Connect and observe

1. Apply checked battery power and attach USB-C. Exit demo, choose **Connect device**, refresh ports, and select the STMicroelectronics Virtual COM Port. A COM number alone does not identify Atlas: the host validates the firmware profile, capabilities, UID and status frames.
2. **Overview** shows live attitude, histories, voltage, SW2 HIGH/LOW and SD detection/mount state. Switch LOW/HIGH describes PF12 electrically; no mechanical ON/OFF orientation is assumed.
3. **Start sensors** deliberately probes previously untested onboard sensors and GNSS once. BLE/radio and fixture tests are separate actions. An absent GNSS antenna means a valid navigation fix is not expected; an absent BLE module is not an installed sensor failure.
4. **Sensors** includes the ten ADC ranks and retained reference diagnostics. A healthy reference uses the H743's 16-bit factory and live values without the erroneous 12-bit conversion. Compare 3V3/PWM/5V/VIN against a meter; ADC readings are not a replacement for electrical qualification.
5. **Navigation** requires a valid fix for position and ground track. **Communications** shows USB, NINA BLE and RFD900x observations. J9's legacy “LoRa” label refers to a serial FHSS radio interface; RSSI, SNR and peer delivery are not fabricated.
6. **Test controls** contains explicit sensor, indicator, GPIO and media commands. **Servo workbench** contains the separate manual PWM procedure. RGB and pyro activation remain unavailable.
7. **Session log** records only after **Start recording**. Stop and export JSONL before closing the server. Records identify host UTC and live/demo source. The 12,000-record cap stops instead of overwriting old evidence.

Invalid or stale measurements are suppressed in instruments; retained observations are labelled. Histories hold 240 frames, about 120 seconds at 2 Hz. MCU status publication rate is not sensor sample rate. Model horn positions are commands/previews, never physical position feedback.

### If connection fails

Close an old server window before relaunching updated Python files; refreshing the browser alone does not replace the server. Select Atlas's USB COM device, not the PC's generic Communications Port. COM numbers can change between computers and after programming. ROM DFU has no application COM port.

The host opens with DTR low, waits 100 ms, clears old input, then raises DTR for a new handshake. This corrects the previous Windows startup race behind `Expecting value: line 1 column 1`. Missing handshakes time out clearly after eight seconds. Malformed telemetry still blocks hardware commands and retains an escaped, bounded rejected-record preview.

### SD card checks

Detection and mounting are separate. In **Test controls**, mount the card first, then read the prepared `ATLAS.TXT`. A missing read-test file is a filesystem error, not proof that the SD slot is broken. The dashboard displays named FatFs errors, controller failure stage, HAL status/error and detect-edge count.

The optional write/read comparison creates a 1,024-byte `ATLASCHK.TST` exclusively and checks its contents. It refuses to overwrite an existing file. It does not format the card. Unmount before removing media; power Atlas off before moving the card to a PC. Safely eject on the PC before returning it to Atlas. The September 11 card check mounted and read `ATLAS.TXT` successfully with the previous 1.1.1 firmware; no SD clock or bus-width change was needed for that result.

## Play the buzzer melody

Startup plays four rising notes once after the buzzer owner starts, even without a dashboard connection. This is a power-on sound, not a flight-readiness annunciation.

**Test controls → Indicators & logic → Imperial March** plays a single 42-note arrangement, 16.5 seconds. Version 1.2.2 restores the high-G repeat and short E–E♭–E turn in the bridge beginning at note 19, corrects the later B♭ landing, and places both opening phrases on four-second boundaries at 120 beats/minute. The closing phrase starts at 13.25 seconds with E♭–F♯–E♭–B♭ before returning to G; this is the owner's accepted Preview C. The owner's preferred lower octave is retained: 311–784 Hz, with a 300 Hz driver minimum. This remains an adaptation of the owner's supplied rough phrases. Timer reload and compares latch together before each tone starts. Firmware 1.1.1 reports its older 33-note/11.36-second sequence.

**Test controls → Indicators & logic → Happy Birthday** requires firmware 1.2.6 and plays the traditional 25-note tune once: C major, 120 beats/minute, 12 seconds, 392–784 Hz. The status names the active song and shows its note count. Both melody buttons are unavailable during playback or active servo PWM; another song is never queued.

**Stop indicators** cancels either melody. USB/DTR loss, a changed session, fault or a new sensor/link command cancels it; there is no replay queue. Polling continues while it plays and late service skips elapsed notes. Firmware update is refused during audio. Status shows MCU playback progress; actual pitch, loudness and differential waveform still require acoustic/scope acceptance.

## Build and first installation

| Root launcher | Output | Capability |
|---|---|---|
| **Build Atlas Firmware.cmd** | `build/BenchMake/Atlas-Bringup.hex` and matching manifest | Diagnostics with PWM/pyro inhibited |
| **Build Atlas ServoBench.cmd** | `build/ServoBenchMake/Atlas-ServoBench.hex` and matching manifest | Diagnostics plus explicitly gated, one-channel manual servo PWM; pyro inhibited |

Builders need the Arm GNU compiler, CMake and GNU Make in addition to Python. They discover installed tool locations and report missing tools; they do not program hardware. Both emit ELF/HEX/BIN/manifest and validate target, vectors, hash and image agreement. The CMake Bringup/ServoBench presets are also available when using Ninja. Normal Debug/Release firmware is not accepted by this dashboard updater.

The launchers use Python directly, so PowerShell script-execution policy does not need to change. On a clone with no build artifacts, the dashboard still opens and connects; build a profile before verifying a new image. Select an explicit manifest for a custom build folder. Relative manifest paths resolve inside this clone.

An image older than 1.1.0 needs **one initial BOOT0/NRST DFU or SWD installation**. Follow [initial programming](startup.md#4-program-the-stm32-over-usb-dfu), verify the exact image, and cold-cycle power. An old application cannot implement a new command until it is replaced.

## Later updates without BOOT0/NRST

With Bringup/ServoBench software-DFU support installed, BOOT0 remains LOW:

1. Stop PWM and indicators, finish commands, and unmount SD. Keep loads isolated and battery/USB stable.
2. Build the desired profile. In **Firmware**, select **Bringup** or **ServoBench**, then **Verify image**. This freezes a validated bank-1-only image. An explicit manifest takes precedence over the selected profile; review the displayed profile and hash.
3. Choose **Update Atlas** and review the concrete image. The serial owner rechecks identity and idle state, then sends one UID-bound bootloader request. Firmware waits for acknowledgement transfer completion and uses a one-shot marker/software reset to enter factory ROM before HAL/RTOS setup.
4. The host requires a single DFU target, pins every programmer command to its DFU serial, and compares physical UID/family with the application handshake before writing. A wrong or ambiguous target aborts.
5. CubeProgrammer downloads and verifies the bounded HEX. The updater performs no mass erase, option-byte change or readout-unprotect. A failed verify does not run or retry the image automatically.
6. ROM 0x91/0x92 permits the application-start request. Other or unreadable ROM versions require a cold power cycle, which the UI reports explicitly. Even a supported ROM may need a cold restart: if the flash verifies but the application COM port does not return, disconnect both USB-C and battery, leave BOOT0 LOW, then restore battery power and USB-C. Reconnect and verify the new profile/version and live data. Do not repeat a verified flash just because the restart did not complete.

The September 11 test verified software-requested programming of 1.2.1 on this board. One ROM 0x92 update returned directly; the latest required the cold restart above. Automatic return is not yet reliably qualified.

A broken application, interrupted update or USB driver problem can still require physical BOOT0/NRST or SWD recovery. Factory ROM owns its own pins during DFU; application output inhibits do not govern ROM. See the same isolation requirements as initial programming. Normal/flight builds have no maintenance command parser and remove the dashboard's update route.

## Engineering details and references

The wire command is `ID bootloader UID0 UID1 UID2`; `software_dfu:true` advertises support. UID matching prevents accidental wrong-device writes; it is not authentication. BLE/radio cannot send these commands. Entry cancels on an expired drain deadline, dropped acknowledgement, session loss or newly unsafe/busy state.

An 8-byte `.atlas_boot` marker in DTCM requires a complementary value and software-reset cause. Cold boots never read uninitialized marker memory. The initial MSP is `0x2001FFE0`, reserving the ROM Go restriction's top 32 bytes; the existing stack/MPU guard remain. GNU and IAR layouts agree, but actual IAR compilation is unverified.

The server binds to loopback, serves a fixed asset allowlist, checks Host/Origin, requires a random session token, and bounds requests/captures. Opening the page never opens a COM port. Optional WebMCP telemetry is read-only.

- ST [AN2606](https://www.st.com/resource/en/application_note/an2606-introduction-to-system-memory-boot-mode-on-stm32-mcus-stmicroelectronics.pdf), H74xxx/75xxx bootloader resources and ROM-version restrictions.
- ST [CubeProgrammer command reference](https://dev.st.com/stm32cube-docs/prog/2.23.0/en/docs/markup/CubeProg_Command_Lines.html), target selection, read, download/verify and Go.
- [Servo bench procedure](SERVO_BENCH.md) and [review record](GROUND_STATION_REVIEW.md), including limitations of host tests and actual bench evidence.

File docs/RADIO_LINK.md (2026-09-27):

# Atlas bench radio connection — 1.4.0

Firmware 1.5.0 retains this acknowledged diagnostic link and adds automatic
[remote sensor telemetry](REMOTE_TELEMETRY.md) in a separate dashboard tab. Pause that
broadcast on both boards before entering guarded AT diagnostics.

The dashboard's **Communications → RFD900x** panel now distinguishes local UART startup
from a verified round trip to another Atlas. Both boards need Bringup or ServoBench
1.4.0. USART3 in both the generated source and CubeMX project uses **57600, 8N1**, matching
the [RFDesign Point-to-Point/SiK factory setting](https://files.rfdesign.com.au/Files/documents/RFD900x%20Peer-to-peer%20V3.X%20User%20Manual%20V1.4.pdf).
The modem's solid green LED establishes RF synchronization; Atlas-level verification
also tests both board UARTs and the peer's application. No modem EEPROM or RF settings
are changed by this update.

## Operation

- Boot starts passive reception. A battery-only board can respond without opening its dashboard.
- **Connect & monitor** performs a test, then issues another every three seconds.
- **Test round trip** supersedes any pending background test and waits up to two seconds
  for a matching response. USB remains responsive; the sensor owner continues sampling.
- A successful test shows peer UID and round-trip milliseconds. A failed UART write and
  a missing peer reply are separate failures. The last explicit test result remains
  visible while monitoring runs.
- **Connected** requires a matching reply less than six seconds old. A failed subsequent
  test clears the connection immediately at its two-second deadline. USB/owner staleness
  suppresses the dashboard's connection claim even if the last stored frame was green.
- **Stop monitoring** clears local connection proof and stops originating tests. The
  board continues to answer valid peer tests. Monitoring is volatile, survives USB
  disconnect, and ends on board reset. It is independent of SW2 and stabilization.
- For local AT identity diagnostics, stop monitoring at both ends and allow the serial
  guard interval. AT access remains blocked while stabilization is enabled.

Both firmware profiles keep their existing output policy. RF traffic cannot enter the
USB console or issue any output, stabilization, storage, settings or bootloader command.
The new protocol carries diagnostic challenges and responses only. ServoBench's saved
calibration, reverse mask, SW2 gates, power checks, PWM timing and standalone operation
are unchanged. The normal application retains its existing radio byte API.

## Wire and timing contract

Each fixed 44-byte frame contains `ATLR`, version 1, type PING=1 or ACK=2, two reserved
zero bytes, sender UID (three uint32), destination UID (three uint32), uint32 sequence,
uint32 originating millisecond timestamp, and CRC-32/ISO-HDLC over the first 40 bytes.
Integers and CRC are little endian. A zero destination is valid for discovery PINGs only.
ACKs must address the full local UID, originate from a different nonzero UID, and match
the outstanding sequence and timestamp before the deadline. CRC provides corruption
detection, **not authentication**; this is not a secure remote-control protocol.

The 44-byte sliding parser handles arbitrary fragmentation/noise without dynamic memory.
Unknown types, versions, reserved bits, CRC failures, local echoes, stale/foreign ACKs
and arbitrary console text do not establish a connection. ACKs are never acknowledged.
There is one reply slot; surplus PINGs are dropped. Replies are limited to one per 100 ms.
Service sends at most one frame per call. A 44-byte UART transfer at 57600 takes about
7.64 ms, with a 20 ms HAL bound; the two-second peer wait is asynchronous. The independent
IO task retains its 5 ms control cadence and existing 100 ms IMU freshness limit.

`hello.radio_link=1` advertises the capability. Radio status includes actual host baud,
monitoring/connected/waiting, last peer/ACK age/RTT, sent/received/replied/acknowledged
counts, timeouts, UART errors/drops, corrupt frames, and a separate last-test sequence,
peer, RTT and result: 0 idle, 1 waiting, 2 acknowledged, 3 timeout, 4 transmit error,
5 cancelled. `ack_age_ms=UINT32_MAX` means no currently retained acknowledgement.

## Verification

Run `Tests/bringup/run_bringup_tests.ps1` for radio protocol, production USB completion,
Python schema/command gates and browser presentation tests, along with existing bench
regressions. Host/service tests and all four build profiles cover shared firmware changes.
See [the review and hardware record](RADIO_LINK_REVIEW.md) for this installation.

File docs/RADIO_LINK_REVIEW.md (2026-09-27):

# Radio link 1.4.0 review and installation record

Scope: two connected Atlas boards, factory RFD900x serial settings, bench communication
only. The user requested at least three reviews. These are focused review passes by
the implementing agent, not independent certification or RF/electrical qualification.

## Review 1 — protocol and evidence

Reviewed frame boundaries, ownership of UIDs/challenges, CRC validation, timeout boundaries,
tick wrap, duplicate/self/foreign replies, simultaneous tests and bounded response traffic.
Connection depends on a matching round trip, never UART-write success or inbound PING alone.
Expired proof is permanently cleared by service, preventing revival after a full tick wrap.
The parser has no command-dispatch path. Tests cover every split point, each damaged byte,
each truncated prefix, arbitrary command text, replay, late ACK, transmit error, peer loss,
monitoring, concurrent two-way tests and response flooding. Passed.

## Review 2 — integration and preservation

Reviewed sole UART ownership, the asynchronous USB completion and queue backpressure,
USB epoch fencing, IMU/service timing, stabilization gates, saved configuration and DFU.
The owner continues sensor work while waiting for RF. Only the three bounded radio
diagnostic operations are exempted from the stabilization maintenance block; local AT
and other maintenance remain blocked. Radio test results are published before USB
completion and cannot be replayed into a new USB session. Production console tests cover
waiting, timeout, successful peer detail, full result queue, disconnect and maintenance
denial. Existing servo, stabilization/persistence, buzzer, IO, USB, storage, expansion and
driver tests passed. A new console test initially assumed a zero storage counter after
earlier tests; corrected it to assert the counter is unchanged, then the suite passed.

## Review 3 — release, dashboard and hardware

Reviewed the final diff, generated USART3 configuration, CMake/IAR source membership,
capability/schema compatibility, dashboard freshness and result presentation, all four
build profiles, frozen image identity and physical target selection. Completed the
installation and hardware checks below on 2026-09-27. Passed.

This pass found two dashboard issues and corrected both: **Stop monitoring** needed the
existing HTTP deliberate-action flag, and historical timeout counts must not label an
intentionally stopped monitor as a current failure. Regression tests exercise both.
Actual dashboard Connect, Test, Stop and restart operations were checked against device
responses. The refreshed Communications page shows the responding peer and a successful
test while the peer runs on battery alone.

## Build and regression results

- Normal Debug, normal Release, Bringup and ServoBench builds passed. USART3 is 57600
  in both generated C and CubeMX; other UART configurations are unchanged.
- Bringup suite passed, including pure-C radio/parser and production console tests,
  nine new Python radio tests, browser presentation tests and existing dashboard,
  ground-station, servo, stabilization, persistence, boot, IO and storage regressions.
- Host driver and service suites passed, including actual USB class/owner, expansion,
  storage and IO implementations. Final radio UI regressions passed after the two
  display/control corrections.
- Repository documentation/source checks and whitespace checks passed.
- Installed ServoBench image uses 239848 bytes of flash and 123672 bytes of DTCM,
  leaving 7400 bytes within the 128 KiB DTCM region.

## Device inventory before installation

| USB port | MCU UID (decimal words) | Previous firmware | Saved stabilization |
|---|---|---|---|
| COM3 | 3342386 / 859001093 / 943273521 | ServoBench 1.3.4 | Enabled, calibrated, reverse mask 15, SD present |
| COM4 | 3407904 / 859001093 / 943273521 | ServoBench 1.2.5 | Not supported by old firmware; SD absent |

Both boards reported SW2 OFF, PWM off, pyro disarmed and SD unmounted before installation.
The owner also confirmed both SW2 switches OFF. COM3 calibration was preserved while
stabilization was temporarily saved OFF for the existing DFU interlock; its prior enabled
state was restored afterward and verified to reload after a later power cycle.

## Installation and hardware results

Both MCU UIDs were checked through the application and again through the ROM bootloader
before programming. Both flash writes verified against the same frozen ServoBench
1.4.0 image. Following the requested full power cycle, both applications enumerated and
reported version 1.4.0 with the radio-link capability. Startup was established by these
application observations, not merely by the programmer's start request.

Installed HEX SHA-256:

```text
7c7f2b85587fa0a2cb4d9fe5ca49a6c27e1c94b7549db6495a8f037d8c54ae88
```

| Check | Observed result |
|---|---|
| COM3-initiated tests | 10/10 acknowledged by COM4; 68–241 ms round trips |
| COM4-initiated tests | 10/10 acknowledged by COM3; 90–300 ms round trips |
| Healthy paired runs | No UART errors, receive drops, invalid frames, transmit failures or test timeouts |
| Sensor/task continuity during those runs | Maximum observed IMU age 10 ms on COM3 and 6 ms on COM4; no task faults or power events |
| Peer powered off | Explicit connect returned a 2000 ms timeout; dashboard showed no peer response and remained responsive |
| Peer restored, battery only | COM4 absent from Windows USB ports; automatic monitoring recovered, and explicit test 63 received its ACK in 75 ms |
| Dashboard Stop and restart | Stop cleared monitoring/connection proof; restart received peer ACK in 176 ms |
| COM3 saved stabilization | Enabled, calibrated, saved, reverse mask 15; preserved across the later power cycle |
| Output state | SW2 OFF, PWM off, pyro disarmed and logic outputs low throughout the radio checks |

COM3 also restarted during the peer-power-off exercise, so this run establishes timeout
and recovery behavior, not an exact measured connected-to-disconnected latency. The
continued monitoring during the deliberate outage accumulated 31 expected timeouts;
these remain historical counters after recovery, not current link failures.

Local evidence is retained under `build/radio-140-*`: preflash inventory, programmer
verification, per-board replies/telemetry, peer-off status, battery-peer recovery and
final dashboard state. Build/test logs use `build/radio-*-tests.log` and
`build/radio-*-build.log`; the final UI capture is `build/radio-dashboard-connected.png`.

Existing functionality was checked through the regression suites, source review and
preserved device settings. Outputs remained off; servo motion and pyro hardware were
not requalified during this radio installation. These are bench communication results,
not an RF range, electrical or general flight qualification.

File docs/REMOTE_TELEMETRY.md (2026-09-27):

# Remote Atlas telemetry — firmware 1.5.0

Both bench profiles now initialize onboard sensors and broadcast a complete read-only
snapshot about once per second. Connect either board by USB and open **Remote Atlas**.
Its peer needs battery power and a paired RFD900x, but no USB cable, dashboard, SW2 change
or remote command. Both boards require 1.5.0. The existing Communications round-trip test
remains available and has its own explicit acknowledgements.

The remote view includes direct accelerometers/gyroscope, magnetometer, barometer,
BNO085 reports/quaternion, GNSS position/fix/PPS, ten ADC channels with raw readings and
voltages, temperature, storage presence/errors, SW2, PWM/stabilization state and faults.
Missing sensors and an indoor GPS without a fix are reported as unavailable, not zeros
or invented positions. Local and remote measurements have separate envelopes and UI
state; remote data cannot set local outputs, answer local commands or refresh USB status.

Sensor startup runs once before stabilization IMU samples are published. Allow startup
to finish before using SW2. Existing saved calibration, switch interlocks, independent
5 ms IO task, 100 ms IMU stale limit and output policies remain in place. GNSS configuration
uses the existing volatile RAM setup; modem settings and SD contents are not changed.
An optional sensor failure does not stop other sensor reporting.

## Packet and redundancy contract

This is an application packet protocol above the modem byte transport, not a forwarded
serial terminal. Every snapshot is 512 bytes, divided into eight 64-byte data shards and
two 64-byte repair shards. Any eight of the ten checked shards recover the snapshot.
Each full 100-byte packet contains:

| Bytes | Field |
|---|---|
| 0–3 | `ATLT` magic |
| 4 / 5 | Packet version 1 / telemetry type 1 |
| 6 / 7 | Shard index 0–9 / data-shard count 8 |
| 8–19 | Source MCU UID, three little-endian uint32 words |
| 20–27 | Random 64-bit source boot identifier |
| 28–31 | uint32 snapshot sequence, wrapping naturally |
| 32–95 | 64 payload/repair bytes |
| 96–99 | CRC-32/ISO-HDLC over bytes 0–95 |

The snapshot has an additional CRC-32 over its first 508 bytes. The first repair shard
is the XOR of all data shards. The second is their weighted sum over GF(256), polynomial
`0x11d`, with coefficients `2^index`. Two missing or CRC-rejected shards can be repaired;
an incomplete or bad whole-snapshot CRC never updates displayed measurements.

The bounded sliding parser resynchronizes after byte loss, insertion, truncation or
noise. Assembly accepts reordered shards, rejects duplicate/older sequences and expires
after 1500 ms. One peer UID is retained for the gateway boot; a different board is counted
as a foreign sender. Peer reboot changes clear the old partial snapshot, while four recent
retired boot identifiers reject delayed packets. CRC/UIDs are integrity/identity checks,
not cryptographic authentication. This protocol contains no control messages.

Boot identifiers use the STM32H743 RNG with a total 20 ms initialization/read bound and
clock/seed error checks. A failure disables local broadcasting while reception remains
available. The temporary HSI48/RNG setup restores its clock selection and does not change
USB or sensor clocks. See ST [RM0433, RNG](https://www.st.com/resource/en/reference_manual/rm0433-stm32h742-stm32h743753-and-stm32h750-value-line-advanced-armbased-32bit-mcus-stmicroelectronics.pdf).

Packets are paced at least 35 ms apart; a complete batch is nominally 1000 UART bytes per
second per direction at 57600 8N1. One UART send is at most 100 bytes, bounded to 25 ms;
there is no peer-response wait, heap allocation, retransmission queue or old-data backlog.
Unfinished outgoing batches older than one second are abandoned in favor of a new snapshot.
Explicit ping/ACK work has priority over a telemetry send in that owner iteration.

## Snapshot schema

All values are little-endian 32-bit words. Signed measurements use two's complement;
`INT32_MIN` means an unavailable scaled measurement. Reserved words are zero. The stable
field offsets are in [atlas_telemetry.h](../App/Inc/atlas_telemetry.h); the laptop mapping is
in [remote_telemetry.py](../tools/bringup/remote_telemetry.py). No C structure padding is sent.

| Words | Contents |
|---|---|
| 0–4 | `TLS1` schema magic, source uptime, firmware version, profile, attempted sensor mask |
| 5–32 | Init results, successful sample counts, error counts, sample statuses and times |
| 33–47 | Direct acceleration in mg, gyro in millidegrees/s, temperature in centidegrees C, magnetic field in nT, pressure in Pa |
| 48–69 | BNO report counts/times/accuracy; acceleration mm/s², gyro milliradians/s, magnetic nT, quaternion W/X/Y/Z in millionths |
| 70–80 | GNSS receive time/count, fix/flags/satellites, lat/lon in 1e-7 degrees, altitude/accuracy in mm, time of week and PPS diagnostics |
| 81–105 | ADC time/count/status/validity, VDDA, die temperature, ten mV channels, packed raw uint16 counts, error/reset/power/fault evidence |
| 106–123 | GPIO/SW2/PWM, stabilization state/up vector, eight pulse widths, SD state/errors, sensor service errors, TX count and startup flag |
| 124–126 / 127 | Reserved / whole-snapshot CRC |

USB publishes a separate `type: remote`, schema 1 record approximately every half second.
It carries gateway/peer identities, boot ID, sequence, receive/assembly times, transport
counters and the hex snapshot. The laptop verifies the snapshot CRC again and validates
the schema before decoding it. Invalid remote records are counted separately from local
USB/control errors. Session recordings retain both record types.

## Freshness and link measurements

**Receiving** requires a fresh gateway/USB envelope and a complete snapshot received less
than 3500 ms ago. Losing either side hides measurements. Each sensor additionally carries
its own validity/count and source timestamp. The UI displays age at capture; its freshness
gate also includes elapsed gateway time and assembly duration. There is no synchronized
one-way clock measurement, so unmeasured time before the first packet is not an exact
sensor-age/latency guarantee. Round-trip latency remains available in Communications.

- **Application packet loss:** missing shard slots divided by expected slots for finalized
  batches. Ten slots per observed batch; forward sequence gaps account for completely
  missing batches when reception resumes. This is not the modem's internal RF loss rate.
- **CRC rejection rate:** rejected CRC candidates divided by checked valid plus CRC-rejected
  framed packets. Bytes that destroy the header may instead become sequence/shard loss.
  This is not a bit error rate.
- **Good/lost snapshots:** complete CRC-checked snapshots versus finalized unrecoverable or
  wholly missing batches. **Repaired** counts parity use; a late original packet can still
  arrive after repair, so repairs do not necessarily imply a finalized missing packet.
- **Throughput:** locally received valid packet bytes, completed useful payload bytes and
  packets per second over a roughly one-second window. Rates drop to zero during silence.
- **Other counters:** duplicate/old/foreign/unsupported packets, observed boot sessions,
  whole-batch CRC failures, UART errors/dropped bytes, host rejections, TX errors and
  abandoned outgoing batches. Hardware RSSI/SNR/bit error rate are not fabricated.

Counters are saturating uint32 totals since the gateway boot. Reconnecting USB does not
reset them. Packet loss before the first observed sequence cannot be measured.

**Pause local broadcast** and **Resume local broadcast** affect only the USB-connected
board and do not change its reception or saved settings. Boot resumes broadcasting.
For guarded AT modem diagnostics, pause telemetry and stop radio monitoring on both
boards first. These diagnostic controls do not change output/stabilization settings.

## Verification

Run `Tests/bringup/run_bringup_tests.ps1`. Tests exercise every one/two-shard erasure,
every packet bit, fragmentation/truncation, bad outer and whole-snapshot CRCs, reboot,
sequence/tick wrap, pacing, stale expiry, gateway/source isolation and UI freshness.
The real C snapshot formatter is decoded by the production Python validator. See
[the three-review and hardware record](REMOTE_TELEMETRY_REVIEW.md) for installation evidence.

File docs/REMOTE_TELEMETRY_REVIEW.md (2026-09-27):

# Remote telemetry 1.5.0 — review and installation record

Requested scope: two Atlas boards exchange read-only sensor/ADC/GNSS/health snapshots,
display the peer in its own dashboard tab, and report delivery/integrity statistics.
Three focused self-review passes are required; these are not independent certification.

## Review 1 — wire format and fault behavior

Completed code inspection and fault-injection tests for fixed packet bounds, CRC coverage,
two-shard erasure repair, fragment/noise resynchronization, sequence/tick wrap, duplicates,
reboots, stale assembly deadlines, finite send pacing and counter semantics. Review fixes:
late shards now expire the batch before acceptance; stale outgoing batches are discarded;
GF inverses are computed once per repair; whole-batch CRC failures count once per batch.
Existing command text has no dispatch path through remote packets. Passed offline.

## Review 2 — firmware integration and source separation

Completed inspection of sensor startup, saved stabilization/IO boundaries, UART ownership,
boot identity, console publication and local/remote validation. Sensors start before the
stabilization IMU is published; startup and individual UART writes retain finite deadlines.
Radio bytes have no control-dispatch path. Snapshot copies and USB records have bounded
storage; a rejected remote snapshot cannot refresh local freshness or complete a command.
The actual C formatter passes production Python decoding with signed, invalid and ADC
boundary values. Existing servo, autonomous stabilization, persistence, USB, storage,
GNSS/BNO and output-inhibit regressions pass. No actuator or SD-record format was changed.
Passed offline; real sensor timing and stack margins remain hardware checks below.

## Review 3 — release and dashboard

Completed final source/build/UI review. Normal Debug and Release, Bringup and ServoBench
builds pass. Host, service, focused review, bring-up, Python and browser model tests pass.
Repository link/header/build-membership checks and `git diff --check` pass. Review fixed
a misleading radio-test error that could overwrite a local broadcast-control failure;
the complete bring-up suite was rerun successfully. The new browser tab was also opened
against real 1.4.0 hardware: it correctly requests the upgrade, displays no fabricated
peer values, disables broadcast controls and produces no browser console errors.

Final ServoBench image: 251,232 flash bytes; DTCM 127,632 / 131,072 bytes (3,440 bytes
unallocated, including the existing statically allocated task stacks in the used figure).
HEX SHA-256: `ce070e207e6d49571dcd3617f343799b398633041b45ed462ec7280cd31f28dd`.
Both COM3 and COM4 identities were matched with fresh SW2 OFF, PWM/pyro/GPIO outputs OFF
and no supervisor faults before installation preparation. Three offline review passes
are complete; live 1.5.0 verification is still required below.
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

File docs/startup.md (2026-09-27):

# Startup — Atlas Rev. 0.1 PCB bring-up

Purpose: take an **assembled STM32H743ZIT6 Atlas board** from unpowered inspection to measured, logged peripheral operation. This is the dedicated bench procedure; you do not need to read ten device guides first.

Major functions covered: build the inhibited diagnostic image; enter STM32 factory USB DFU; program and verify flash; connect the local dashboard; test power, GPIO, buzzer, sensors, RTC, SD, BLE and GNSS; diagnose failures; preserve evidence. Optional external-bus/radio tests come last. **RGB, PWM and pyro actuation are unavailable in the ordinary Bringup image; the confirmed rev-0.1 Q6-Q8 LED defect is held low in software.** The separate 1.2.1 [ServoBench procedure](SERVO_BENCH.md) adds reviewed manual servo PWM only after measured supply and free-motion checks; it is not the default procedure below.
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

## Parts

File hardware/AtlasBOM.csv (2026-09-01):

Reference | Value | DNP | Exclude from BOM | Exclude from Board | Footprint | Description
BZ1 | PKMCS0909E48H0-R1 |  |  |  | PKMCS0909E4000-R1:PKMCS0909E4000-R1_MUR | Buzzer, polarized
C1 | 22p |  |  |  | Capacitor_SMD:C_0402_1005Metric | Unpolarized capacitor
C2,C64 | 100p |  |  |  | Capacitor_SMD:C_0402_1005Metric | Unpolarized capacitor
C3,C9 | 47n |  |  |  | Capacitor_SMD:C_0402_1005Metric | Unpolarized capacitor
C4,C48 | 10u |  |  |  | Capacitor_SMD:C_1210_3225Metric | Unpolarized capacitor
C5 | .22u |  |  |  | Capacitor_SMD:C_0402_1005Metric | Unpolarized capacitor
C6,C7,C12,C13,C18,C19,C54,C56,C59,C60,C77,C88,C91,C96,C97,C98 | 22u |  |  |  | Capacitor_SMD:C_1206_3216Metric | Unpolarized capacitor
C8,C10,C14,C20,C27,C28,C31,C32,C33,C34,C35,C36,C37,C38,C39,C40,C41,C42,C43,C44,C50,C53,C58,C62,C66,C68,C74,C78,C79,C81,C82,C83,C85,C87,C89,C90,C92,C93,C100,C104,C105 | 100n |  |  |  | Capacitor_SMD:C_0402_1005Metric | Unpolarized capacitor
C11 | 56p |  |  |  | Capacitor_SMD:C_0402_1005Metric | Unpolarized capacitor
C15,C57 | 2.2u |  |  |  | Capacitor_SMD:C_0402_1005Metric | Unpolarized capacitor
C16,C55 | 10n |  |  |  | Capacitor_SMD:C_0805_2012Metric | Unpolarized capacitor
C17,C26,C29,C45,C61,C63,C75,C76,C94,C103 | 1u |  |  |  | Capacitor_SMD:C_0603_1608Metric | Unpolarized capacitor
C21 | 4.7u |  |  |  | Capacitor_SMD:C_0805_2012Metric | Unpolarized capacitor
C22,C23 | 30p |  |  |  | Capacitor_SMD:C_0402_1005Metric | Unpolarized capacitor
C24,C25,C65 | 10p |  |  |  | Capacitor_SMD:C_0402_1005Metric | Unpolarized capacitor
C30,C67,C84,C86,C95 | 10u |  |  |  | Capacitor_SMD:C_0805_2012Metric | Unpolarized capacitor
C46 | 4.7n |  |  |  | Capacitor_SMD:C_0402_1005Metric | Unpolarized capacitor
C47 | 1u |  |  |  | Capacitor_SMD:C_0402_1005Metric | Unpolarized capacitor
C51,C52 | 2.2u |  |  |  | Capacitor_SMD:C_0603_1608Metric | Unpolarized capacitor
C69,C70,C71,C72,C73 | 10nf |  |  |  | Capacitor_SMD:C_0402_1005Metric | Unpolarized capacitor
C80 | 10n |  |  |  | Capacitor_SMD:C_0603_1608Metric | Unpolarized capacitor
D1 | RClamp0501B |  |  |  | Diode_SMD:D_SOD-882 | Bidirectional transient-voltage-suppression diode
D2 | SMAJ9.0A |  |  |  | Diode_SMD:D_SMA | 400W unidirectional Transient Voltage Suppressor, 9.0Vr, SMA(DO-214AC)
D3 | SMBJ18CA |  |  |  | Diode_SMD:D_SMB | Bidirectional transient-voltage-suppression diode
D4,D7 | ESD5Z3.3T5G |  |  |  | Diode_SMD:D_SOD-523 | ESD Protection Diode, SOD-523
D5 | Cree LED CLV1A-FKB-CK1VW1DE1BB7C3C3 |  |  |  | LED_SMD:LED_Cree-PLCC4_3.2x2.8mm_CCW | Cree PLCC4 3 in 1 SMD LED
D6,D8 | ESD9B5.0ST5G |  |  |  | Diode_SMD:D_SOD-923 | ESD protection diode, 5.0Vrwm, SOD-923
FB1,FB2,FB4 | FerriteBead |  |  |  | Resistor_SMD:R_0603_1608Metric | Ferrite bead
H1,H2,H3,H4 | MountingHole |  | Excluded from BOM |  | MountingHole:MountingHole_3.2mm_M3_DIN965_Pad | Mounting Hole without connection
J1 | XT60PB-M |  |  |  | Connector_AMASS:AMASS_XT60-M_1x02_P7.20mm_Vertical | Generic connector, single row, 01x02, script generated
J2 | USB_C_Receptacle_USB2.0_14P |  |  |  | Connector_USB:USB_C_Receptacle_HRO_TYPE-C-31-M-12 | USB 2.0-only 14P Type-C Receptacle connector
J3 | 1040310811 |  |  |  | Connector_Card:microSD_HC_Molex_104031-0811 | Micro SD Card Socket with one card detection pin
J5,J10,J11,J12,J13,J14 | Conn_01x02_Socket |  |  |  | 393570002:CONN_SD-39357-001_02P_MOL | Generic connector, single row, 01x02, script generated
J6,J15,J16,J17,J18,J21 | PEC03SAAN |  |  |  | Connector_PinHeader_2.54mm:PinHeader_1x03_P2.54mm_Vertical | Generic connector, single row, 01x03, script generated
J7,J8,J22,J23 | Screw_Terminal_01x02 |  |  |  | 393570002:CONN_SD-39357-001_02P_MOL | Generic screw terminal, single row, 01x02, script generated (kicad-library-utils/schlib/autogen/connector/)
J9 | Conn_01x04 |  |  |  | Connector_JST:JST_GH_SM04B-GHS-TB_1x04-1MP_P1.25mm_Horizontal | Generic connector, single row, 01x04, script generated (kicad-library-utils/schlib/autogen/connector/)
J19,J20 | 3 Pin PWM Header |  |  |  | Connector_PinHeader_2.54mm:PinHeader_1x03_P2.54mm_Vertical | Generic connector, single row, 01x03, script generated
J24 | Screw_Terminal_01x03 |  |  |  | 393570003:CONN_SD-39357-001_03P_MOL | Generic screw terminal, single row, 01x03, script generated (kicad-library-utils/schlib/autogen/connector/)
J25 | Screw_Terminal_01x04 |  |  |  | 393570004:CONN_SD-39357-001_04P_MOL | Generic screw terminal, single row, 01x04, script generated (kicad-library-utils/schlib/autogen/connector/)
J26 | Screw_Terminal_01x06 |  |  |  | 393570006:CONN_SD-39357-001_06P_MOL | Generic screw terminal, single row, 01x06, script generated (kicad-library-utils/schlib/autogen/connector/)
J27 | SMA |  |  |  | Connector_Coaxial:SMA_Amphenol_901-144_Vertical | coaxial connector (BNC, SMA, SMB, SMC, Cinch/RCA, LEMO, ...)
J28,J29 | 15910100 |  |  |  | 15910100:CONN_713080000-SD_10_M6p10_MOL
L1 | 10u |  |  |  | Inductor_SMD:L_Coilcraft_XAL5050-XXX | Inductor
L2 | 1.8u |  |  |  | XAL6030-182MEC:IND_XAL6030-182MEC | Inductor
L3 | 4.7u |  |  |  | Inductor_SMD:L_Coilcraft_XAL4030-XXX | Inductor
L5 | 27n |  |  |  | Inductor_SMD:L_0402_1005Metric | Inductor
Q1,Q2,Q3,Q4,Q5 | DMN3404LQ-7 |  |  |  | Package_TO_SOT_SMD:SOT-23 | N-MOSFET transistor, gate/drain/source
Q6,Q7,Q8 | DMN3404L-7 |  |  |  | Package_TO_SOT_SMD:SOT-23 | N-MOSFET transistor, drain/source/gate
R1 | 1.54k |  |  |  | Resistor_SMD:R_0402_1005Metric | Resistor
R2 | 4.22k |  |  |  | Resistor_SMD:R_0402_1005Metric | Resistor
R3,R9 | 40.2k |  |  |  | Resistor_SMD:R_0402_1005Metric | Resistor
R4 | 365k |  |  |  | Resistor_SMD:R_0402_1005Metric | Resistor
R5 | 0 |  |  |  | Resistor_SMD:R_0402_1005Metric | Resistor
R6,R11,R17,R35,R36,R37,R38,R39,R47,R49,R54,R63,R67,R74,R75,R84,R86,R88,R90,R92,R94,R96,R98,R107,R108,R110,R117,R120,R123,R124,R125,R128,R130 | 100k |  |  |  | Resistor_SMD:R_0402_1005Metric | Resistor
R7 | 130k |  |  |  | Resistor_SMD:R_0402_1005Metric | Resistor
R8,R10,R12,R16,R18,R21,R77,R78,R79,R80,R99,R126,R127 | 10k |  |  |  | Resistor_SMD:R_0402_1005Metric | Resistor
R13,R14,R113,R114 | 100 |  |  |  | Resistor_SMD:R_0402_1005Metric | Resistor
R15,R20 | 5.1k |  |  |  | Resistor_SMD:R_0402_1005Metric | Resistor
R19 | 23.2k |  |  |  | Resistor_SMD:R_0402_1005Metric | Resistor
R22,R23,R25,R26,R76 | 47k |  |  |  | Resistor_SMD:R_0402_1005Metric | Resistor
R24,R29,R30,R50,R51,R112 | 47 |  |  |  | Resistor_SMD:R_0402_1005Metric | Resistor
R27 | 33k |  |  |  | Resistor_SMD:R_0402_1005Metric | Resistor
R28 | 82k |  |  |  | Resistor_SMD:R_0402_1005Metric | Resistor
R31,R105 | 150 |  |  |  | Resistor_SMD:R_0402_1005Metric | Resistor
R32 | 133k |  |  |  | Resistor_SMD:R_0402_1005Metric | Resistor
R33 | 13.7k |  |  |  | Resistor_SMD:R_0402_1005Metric | Resistor
R34 | 1.5M |  |  |  | Resistor_SMD:R_0402_1005Metric | Resistor
R40,R41,R42,R43 | 2.2k |  |  |  | Resistor_SMD:R_0402_1005Metric | Resistor
R44,R61,R65,R70,R72,R102,R104,R106 | 220 |  |  |  | Resistor_SMD:R_0402_1005Metric | Resistor
R45,R60,R64,R68,R69 | 25k |  |  |  | Resistor_SMD:R_0402_1005Metric | Resistor
R46,R62,R66,R71,R73 | 470k |  |  |  | Resistor_SMD:R_0402_1005Metric | Resistor
R48 | 820k |  |  |  | Resistor_SMD:R_0402_1005Metric | Resistor
R52,R53,R55,R56,R57 | 47.5k |  |  |  | Resistor_SMD:R_0402_1005Metric | Resistor
R58 | 270k |  |  |  | Resistor_SMD:R_0402_1005Metric | Resistor
R59 | 33.2k |  |  |  | Resistor_SMD:R_0402_1005Metric | Resistor
R81,R82 | 4.7k |  |  |  | Resistor_SMD:R_0402_1005Metric | Resistor
R83,R85,R87,R89,R91,R93,R95,R97 | 50 |  |  |  | Resistor_SMD:R_0402_1005Metric | Resistor
R100 | 500 |  |  |  | Resistor_SMD:R_0402_1005Metric | Resistor
R101,R103 | 91 |  |  |  | Resistor_SMD:R_0402_1005Metric | Resistor
R109,R111,R129,R131,R132,R134,R135,R136,R137,R138,R139,R140,R141,R142,R143 | 1k |  |  |  | Resistor_SMD:R_0402_1005Metric | Resistor
R115,R116 | 33 |  |  |  | Resistor_SMD:R_0402_1005Metric | Resistor
R118,R119 | 49.9k |  |  |  | Resistor_SMD:R_0402_1005Metric | Resistor
R121,R122 | 105k |  |  |  | Resistor_SMD:R_0402_1005Metric | Resistor
R133 | 19 |  |  |  | Resistor_SMD:R_0402_1005Metric | Resistor
R144 | 22k |  |  |  | Resistor_SMD:R_0402_1005Metric | Resistor
SW2 | SW_SPDT |  |  |  | Button_Switch_THT:SW_Slide_SPDT_Angled_CK_OS102011MA1Q | Switch, single pole double throw
TP1 | VIN_RAW |  |  |  | TestPoint:TestPoint_Pad_D1.0mm | test point
TP2 | GND |  |  |  | TestPoint:TestPoint_Pad_D1.0mm | test point
TP3 | VIN_PROT |  |  |  | TestPoint:TestPoint_Pad_D1.0mm | test point
TP4 | 8V4_PWM |  |  |  | TestPoint:TestPoint_Pad_D1.0mm | test point
TP5 | 3V3_SYS |  |  |  | TestPoint:TestPoint_Pad_D1.0mm | test point
TP6 | 3V3_AUX |  |  |  | TestPoint:TestPoint_Pad_D1.0mm | test point
TP7 | 5V_SYS |  |  |  | TestPoint:TestPoint_Pad_D1.0mm | test point
TP8 | BOOT0 |  |  |  | TestPoint:TestPoint_Pad_D1.0mm | test point
TP9 | BLE_SWDCLK |  |  |  | TestPoint:TestPoint_Pad_D1.0mm | test point
TP10 | BLE_SWDIO |  |  |  | TestPoint:TestPoint_Pad_D1.0mm | test point
TP11 | LSM6DSV16BTR_INT2 |  |  |  | TestPoint:TestPoint_Pad_D1.0mm | test point
TP12 | GNSS_SAFEBOOT |  |  |  | TestPoint:TestPoint_Pad_D1.0mm | test point
TP13 | NRST |  |  |  | TestPoint:TestPoint_Pad_D1.0mm | test point
U1 | ADXL375BCCZ |  |  |  | ADXL375BCCZ:LGA_CC-14-1_ADI
U2 | SN74LVC1G32DBVR |  |  |  | Package_TO_SOT_SMD:SOT-23-5 | Single OR Gate, Low-Voltage CMOS
U3 | LM76003 |  |  |  | Package_DFN_QFN:Texas_RNP0030B_WQFN-30-1EP_4x6mm_P0.5mm_EP1.8x4.5mm_ThermalVias | 3.5A synchronous buck regulator, 3.5..60Vin, 300kHz..2.2MHz switching frequency, CCM/DCM & PFM at light load, WQFN-30
U4 | LM76002 |  |  |  | Package_DFN_QFN:Texas_RNP0030B_WQFN-30-1EP_4x6mm_P0.5mm_EP1.8x4.5mm_ThermalVias | 2.5A synchronous buck regulator, 3.5..60Vin, 300kHz..2.2MHz switching frequency, CCM/DCM & PFM at light load, WQFN-30
U5 | MP8772GQ-P |  |  |  | MP8772GQ:QFN-16_MP8772GQ-P_MNP
U6 | STM32H743ZIT6 |  |  |  | Package_QFP:LQFP-144_20x20mm_P0.5mm | STMicroelectronics Arm Cortex-M7 MCU, 2048KB flash, 1024KB RAM, 480 MHz, 1.62-3.6V, 114 GPIO, LQFP144
U7 | TPD6E05U06RVZ |  |  |  | Package_SON:Texas_R-PUSON-N14 | 6-Channel ESD Protection for Super-Speed USB 3.0 Interface, USON-14
U9 | MMC5983MA |  |  |  | MMC5983MA:MMC5983MA_MEM
U10,U17 | TPD4E05U06DQA |  |  |  | Package_SON:USON-10_2.5x1.0mm_P0.5mm | 4-Channel ESD Protection for Super-Speed USB 3.0 Interface, USON-10
U11 | TPS16850VMAR |  |  |  | TPS16850AVMAR:IC_TPS16850VMAR
U12 | BNO085 |  |  |  | BNO085:LGA-28_CEV
U14 | MS561101BA03-50 |  |  |  | Package_LGA:LGA-8_3x5mm_P1.25mm | Barometric pressure sensor, 10cm resolution, 10 to 1200 mbar, I2C and SPI interface up to 20MHz, LGA-8
U15,U18,U19,U20 | TPS2553DBVR |  |  |  | TPS2553DBVR:DBV6
U16 | USBLC6-2SC6 |  |  |  | Package_TO_SOT_SMD:SOT-23-6 | Very low capacitance ESD protection diode, 2 data-line, SOT-23-6
U21 | NINA-B112-05B |  |  |  | NINA-B112-04B:XCVR_NINA-B112-04B
U23 | NEO-M9N |  |  |  | RF_GPS:ublox_NEO | GNSS Module NEO M8, VCC 2.7V to 3.6V
U27 | LSM6DSV16BTR |  |  |  | LSM6DSV16BXTR:PQFN50P250X300X74-14N
Y1 | 8MHz Crystal (ABM3B-8.000MHZ-18-D2Y-T) |  |  |  | Crystal:Crystal_SMD_Abracon_ABM3B-4Pin_5.0x3.2mm | Four pin crystal, GND on pins 2 and 4
Y2 | 32.768 kHz Crystal (ABS07-32.768KHZ-9-T) |  |  |  | ABS07-32.768KHZ-T:CAP_ABS07-32.768KHZ-T_ABR | Two pin crystal

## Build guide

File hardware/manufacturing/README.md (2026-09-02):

# Candidate Manufacturing Package

These files were copied together from the source folder's `Trinity/Manufacturing Files/` directory. They are preserved as a coherent candidate package, but they have not been independently confirmed as the exact package submitted for the already manufactured board.

The import decision and firmware/hardware authority rules are centralized in [Provenance](../../docs/reference/PROVENANCE.md) and [Hardware](../../docs/reference/HARDWARE.md). This manifest does not authorize fabrication.

## Contents

- Six copper layers: `F_Cu`, `In1_Cu` through `In4_Cu`, and `B_Cu`.
- Front/back solder mask and silkscreen.
- Front/back paste layers.
- Edge cuts.
- Plated and non-plated drill files.
- KiCad Gerber job metadata.
- JLCPCB BOM workbook.
- JLCPCB component-placement CSV.
- KiCad all-positions CSV.
- `SHA256SUMS.txt` for checking that the preserved package has not changed.

## Before fabrication or assembly

1. Identify and archive the exact files and assembly options used for the as-built board, if available.
2. Confirm schematic, BOM, CPL, Gerbers, drill files, stack-up, dimensions, and board revision all describe the same design.
3. View every Gerber layer and both drill files in an independent viewer.
4. Check connector orientation, pin 1, polarity, and rotation for every IC, diode, LED, polarized capacitor, module, and bottom-side component.
5. Reconcile the JLCPCB BOM against current availability and approved substitutions.
6. Reconcile the CPL against the assembled reference board or a reviewed 3D/placement view.
7. Confirm panelization, controlled impedance, copper weight, finish, thickness, and assembly-side options.
8. Record reviewer names, date, package hash, and the final order identifier.

Verify the preserved files from this directory with a SHA-256 tool and compare the result with `SHA256SUMS.txt` before review or ordering.

The source tree also contained a second CPL with the same row count but 98 differing rows. It is intentionally not included here. Do not substitute another CPL by filename alone.

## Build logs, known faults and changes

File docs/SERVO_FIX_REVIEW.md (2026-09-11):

# ServoBench 1.2.5 — direct angle moves

September 11, 2026. Three sequential author reviews; these are not independent reviews or flight qualification.

## Result and earlier findings

Every accepted position selection now writes its destination pulse once, allowing the KST's internal controller to handle motion. The 600 µs/s software ramp is removed. This follows the owner's observation that enabling at 1520 µs moved quickly and smoothly, while ordinary moves stuttered. A new regression failed on the installed 1.2.4 ramp and passes on the direct implementation. Physical acceptance of 1.2.5 is recorded separately below.

The dashboard offers −50°, −25°, 0°, +25° and +50° buttons and whole-degree numeric entry. One click, Move or Enter sends one target; typing only previews. There is no streaming slider, motion timer, retained target queue, retry or keepalive. The KST factory nominal mapping is 1000/1500/2000 µs for −50°/0°/+50°. Enable retains 1520 µs and displays its nominal +2° honestly. Models display commands, not measured shaft angles.

The earlier connector correction is retained: PCB PWM 1 at the right corresponds to old schematic net PWM7; the complete right-to-left mapping is 7,8,1,2,3,4,5,6. One route table governs pin selection, compares and shutdown. The owner physically confirmed PWM1. Other connectors have software-model coverage, not individual electrical verification.

The earlier 1.2.2 output-owner loop accidentally applied its normal 8.4 V policy after the ServoBench 8.55 V policy. That was corrected and covered by a failing-before/passing-after owner-loop regression. An unloaded 1.2.3 test then stopped at an actual retained 8559 mV ADC sample. The owner approved 16-sample hardware averaging, delivered in 1.2.4. This averaging and the exact 8550/8551 mV boundary remain in 1.2.5.

Later slider fixes corrected a browser timer receiver error and reduced polling payloads. The owner still reported jerky dragging, so those observations are not counted as a physical smooth-motion success. The obsolete slider/scheduler has been replaced completely. The approved Preview C melody and its 42 notes / 16.5 seconds are unchanged.

## Review 1 — firmware, routes and shutdown

Reviewed the 1.2.4-to-1.2.5 source delta and all paths into the output owner. SET retains command age, cancellation/output epochs, USB session, voltage/fault checks, one-channel activation and configured pulse bounds. It writes the compare and both reported pulse fields directly. Unlike initial enable, an active SET does not reset CNT, issue EGR.UG, remux the pin or restart the timer. The bundled HAL enables compare preload for each TIM1/TIM3 PWM channel; the next PWM period adopts the destination.

Strict C regressions pass for all eight expected physical routes, direct forward/reverse targets, steady holds, 1000/1500/2000 µs positions, narrower windows and invalid bounds. Timer counter, update-event, channel-enable and running-control registers remain unchanged during SET. The new direct-target assertion fails on the old ramp. Stop-before-queued-enable/move, USB epochs/loss, zero/invalid/stale ADC, reference/monitor failure, 8550 accepted / 8551 stopped, 3 s idle including tick wrap and 30 s session expiry still pass. The complete owner loop also passes. Normal flight policy tests retain their original voltage and permission requirements.

## Review 2 — dashboard and host

The 23 inert servo host/protocol tests pass, including one request per full-range target, identity/control epochs, delayed HTTP commands crossing Stop, strict boolean `servo_direct` capability and legacy Stop compatibility. Both host and UI require the direct capability, corrected layout, 16-sample averaging and 8550 mV policy before enable/move. Old telemetry remains viewable; Stop remains available.

Production UI handlers pass inert DOM tests for all 101 whole-degree conversions, numeric preview, exactly one command per selection, no timer/queue/replay, in-flight rejection, and fresh/visible/voltage/pending/batch/session gates. Actual browser preview checks show +50° → 2000 µs and −12° → 1380 µs with no JavaScript errors. These preview checks do not actuate hardware. The full Bringup and normal service suites pass, including real console serialization, USB core/owner, storage and expansion boundaries, and buzzer controls.

## Review 3 — builds and release consistency

ServoBench and ordinary Bringup build and pass manifest/HEX/BIN/vector/profile checks. Normal Debug and Release also build successfully. The first normal Debug post-link attempt lacked the ARM objcopy directory on PATH; after adding the installed toolchain directory both normal builds completed. No source workaround was needed.

| Artifact | Bytes | SHA-256 of HEX |
|---|---:|---|
| Atlas-ServoBench 1.2.5 | 218548 | `2e7b638ba81cd0ca3666da2d28deeea4e0932e3e07400f87c4190ea39bbdb3c7` |
| Atlas-Bringup 1.2.5 | 216272 | `eeca38861f057f5431791aaec7ad4258bcd1f52e84652a479f87fa055ef754f5` |

ServoBench uses 122200 bytes of DTCM and ordinary Bringup 122184 bytes. Normal Debug uses 205864 flash bytes / 90136 DTCM bytes; Release uses 106236 flash bytes / 90112 DTCM bytes. Builds and models do not establish maximum live stack use or electrical qualification.

The installer checks all 437 protected source/image files against the previous installed manifest, backs up every changed file and verifies installed hashes. Existing uncommitted work is retained. The console delta was checked to contain only direct-capability metadata and the updated servo reply, preserving the accepted melody exactly. No commit or push is part of this work.

## Live acceptance and portability

1.2.4 previously passed an unloaded eight-channel command test and a narrow physical PWM1 repeat in which the owner reported smooth movement and steady holds. This did not establish smooth wider slider control; the later failures above remain part of the record.

1.2.5 was programmed and verified on the matched board UID `00330032 33335105 38393631`, DFU serial `200364500000`. ROM 0x92 accepted the application-start request but USB did not return; the owner cold-restarted battery and USB, then the host confirmed live `servo_bench` 1.2.5 with `servo_direct:true`. All eight unloaded channels accepted 1000/2000/1500 µs targets and Stop, followed by an actual 3 s idle cutoff. After the owner reconnected the free servo to PWM1, the actual browser buttons commanded −25°, +25°, 0°, −50°, +50°, 0°, then Stop. The owner reported “Yes—quick and smooth.” Accepted targets equalled reported pulse destinations throughout the captured active frames, with no ADC/task faults, and the final mask and all pulse fields were zero. This is physical motion acceptance on PWM1, not a calibrated angle or oscilloscope measurement. Portable extraction checks are recorded in the release package result. Factory-ROM application restart is not reliably qualified: a verified flash may need a battery-and-USB cold restart with BOOT0 LOW. Do not repeat a verified flash solely because USB did not return. Only the unrestricted PWM1 servo is available for physical motion checks. No oscilloscope waveform, calibrated full-travel measurement, all-eight-connector electrical test or second physical laptop result is claimed.

During the physical button sequence, the ADC recorded two PWM-supply readings below 4.8 V: 2407 mV at MCU tick 263434 and 2367 mV at tick 264144, during the +25° and 0° commands. The 3V3 reading stayed near 3.35 V and no ADC or task fault was reported. These are telemetry observations, not scope-confirmed rail minima or durations; supply transient behavior remains unqualified. The owner-selected voltage policy accepts usable nonzero readings below 8.55 V, so no new low-voltage gate was added.

See [the servo procedure](SERVO_BENCH.md) and [portable Windows setup / updating](GROUND_STATION.md).

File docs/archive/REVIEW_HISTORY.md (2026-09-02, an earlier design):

# Historical review archive

These six sequential author self-reviews describe earlier repository states. Their **pass conclusions, build figures, timing claims and completeness claims are superseded** by the [current review report](../REVIEW_REPORT.md) and [Systems](../SYSTEMS.md). They are not independent reviews or hardware qualification.

Historical text is retained below; links are rebased to the current documentation layout. Follow Git commit `0dbc245` to recover the exact original files and original link destinations. The archived prose is evidence of what was previously claimed, not current operational guidance.

- [Review 1](#review-1)
- [Review 2](#review-2)
- [Review 3](#review-3)
- [Review 4](#review-4)
- [Review 5](#review-5)
- [Review 6](#review-6)

## Review 1

### Review 1 — Hardware and Protocol Conformance

| Field | Value |
|---|---|
| Date | 2026-09-01 |
| Baseline | Atlas Flight Computer schematic Rev. 0.1, dated 2026-03-19 |
| Scope | Fitted sensors, GNSS, NINA-B112, external RFD900x interface, RGB LED, and differential buzzer |
| Method | Independent pass over schematic-derived nets, generated peripheral configuration, driver transactions, and primary manufacturer manuals |
| Outcome | Pass for implementation consistency; physical acceptance remains on hold |

#### Questions applied

1. Does the code address the exact fitted part, bus instance, address/chip select, interrupt, reset, and output polarity shown by the hardware reference?
2. Are startup commands, register encodings, byte order, checksums, reset delays, mode transitions, and configuration readbacks consistent with the primary manufacturer interface documents?
3. Can an acknowledgement, echo, timeout, or stale software flag be mistaken for proof of active configuration?
4. Does ordinary boot avoid unrequested nonvolatile writes and unsafe output activity?

#### Coverage and result

| System | Conformance focus | Result |
|---|---|---|
| ADXL375 | SPI2 mode 3, PG12 select, `0xE5` identity, fixed format, ODR, data-ready polling, XYZ little-endian burst | Source consistent; register emulator passed; bench pending |
| LSM6DSV16B | SPI3 mode 3, PG10 select, PG2 INT1, `0x71` identity, reset, ODR/FS, direct-output map | Source consistent; register emulator passed; bench pending |
| MMC5983MA | SPI2 mode 3, PG11 select, `0x30` identity, control-bit encodings, 18-bit packing, SET/RESET | Source consistent; register emulator passed; bench pending |
| MS5611-01BA03 | I2C1 address `0x77`, reset/PROM sequence, CRC-4, conversion commands, signed 64-bit compensation | Source consistent; command/math emulator passed; bench pending |
| BNO085 | I2C1 address `0x4B`, PB13 reset, PG0 interrupt, CEVA SHTP/SH-2 adapter, report IDs and reset handling | Source and pinned library consistent; physical SHTP trace pending |
| NEO-M9N | USART1, TIM2 PPS capture, UBX checksum, MON-VER, NAV-PVT offsets, RAM CFG keys and typed values | Source consistent; parser/config/PPS tests passed; bench pending |
| NINA-B112-05B | USART6 RTS/CTS, normal boot straps, reset/DSR/DTR polarity, R55 AT syntax, SPS role/server/start mode | Source consistent; AT/profile/mode tests passed; bench pending |
| RFD900x header | USART3 transparent transport, SiK escape guards, local AT access, readback before save | Source consistent; AT emulator passed; modem/region/paired link pending |
| RGB LED | PB6/PB7/PD14 low-side transistor gates and active-high logical colors | Runtime GPIO ownership and logic test passed; electrical color/polarity pending |
| Buzzer | PE5/PE6 TIM15 differential drive, opposite PWM modes, bounded frequency and silent stop | Timer contract test passed; waveform/load measurement pending |

#### Findings resolved in this baseline

- **R1-01 — Radio terminology:** The J9 interface had been described informally as LoRa. Hardware and RFDesign documentation identify an external RFD900x/SiK frequency-hopping serial modem; code and documentation now use `RFD900x` and explicitly reject a LoRa/LoRaWAN claim.
- **R1-02 — GNSS configuration proof:** A CFG-VALSET acknowledgement alone was insufficient. Initialization now performs CFG-VALGET against RAM and requires all six typed keys to match, independent of response order.
- **R1-03 — BLE operating mode:** u-connectXpress R55 defines `UMSM=1` as ordinary Data mode and `UMSM=2` as Extended Data Mode. The saved SPS profile uses `UMSM=1`; wired `AT&D1` command entry requires the unsolicited `OK` before a fresh AT probe.
- **R1-04 — BLE persistence:** Persistent configuration now uses `AT&W`, restart, complete profile re-read, an operational DSR transition check, and verified `ATO1` return rather than treating write acknowledgements as durable proof.
- **R1-05 — LSM6DSV16B output order:** The direct accelerometer registers are Z, Y, X at `0x28`, `0x2A`, `0x2C`; the driver and test retain this non-obvious map explicitly.
- **R1-06 — LED pin ownership:** CubeMX stages the LED pins as TIM4 alternate functions. `AtlasLed_Init()` now establishes fail-dark output levels and deliberately reclaims all three pins as GPIO before color control.
- **R1-07 — BNO085 asynchronous faults:** CEVA transport and reset counters are surfaced through the adapter; newly observed protocol/I/O/decode/reset faults latch the board runtime fault instead of being silently ignored.

#### Primary references

The module guides under [Module Firmware Guides](../README.md#device-references) link the exact Analog Devices, ST, MEMSIC, TE Connectivity, CEVA, u-blox, RFDesign, and Murata primary documents used for this pass. No secondary tutorial was treated as protocol authority.

#### Residual hold points

- No assembled Atlas board was available to confirm population, rework state, bus electrical behavior, interrupt polarity, reset timing, output polarity, or sensor orientation.
- No BNO085 SHTP trace, GNSS fix/PPS measurement, BLE RF/SPS session, or RFD900x paired-radio session has been captured.
- Nominal sensor scaling is not calibration, and no body-frame transform is approved.
- Passing this review therefore supports implementation and host-protocol status only. Follow [Module Bring-up and Acceptance](../SYSTEMS.md) before promoting any system to bench-verified.

## Review 2

### Review 2 — Implementation, Failure Paths, and Builds

> Applicability note (2026-09-01 RTOS integration): references below to the former foreground main loop are historical. Review 4 supersedes that execution model with a highest-priority RTOS supervisor as the sole watchdog owner.

| Field | Value |
|---|---|
| Date | 2026-09-01 |
| Scope | Project-owned firmware, CEVA integration, target build inputs, host tests, bounded-failure behavior, and memory evidence |
| Method | Fresh source pass, strict host compile/tests, clean Debug/Release Arm GNU builds, source-membership/XML checks, API scan, and compiler stack-frame inspection |
| Outcome | Pass for the tested toolchain; IAR compilation and hardware execution remain pending |

#### Questions applied

1. Are externally supplied lengths, indices, parser states, queues, waits, and response buffers bounded and fail-visible?
2. Do interrupts remain short, with protocol parsing and blocking bus work deferred to foreground context?
3. Can a partial response, command echo, asynchronous reset, ring overflow, or secondary-channel failure be reported as success?
4. Do runtime failures reach the board-level fault latch and prevent unconditional watchdog refresh?
5. Are all project-owned and pinned CEVA units present in both supported build descriptions?

#### Findings resolved in this baseline

- **R2-01 — BLE response truncation:** A caller response buffer overflow was counted but could previously be followed by terminal `OK`. `AtlasBle_Command()` now returns `ATLAS_ERROR_OVERFLOW` immediately for either line or destination truncation; a regression test proves `command_ok` remains unchanged.
- **R2-02 — Radio echo-only evidence:** `ATI`/`ATI5` terminal `OK` with only local command echo did not prove an identity/settings response. The typed helpers now require substantive non-echo content and increment `malformed_responses` on failure.
- **R2-03 — Coherent PPS reads:** Foreground PPS consumers use a short critical-section snapshot so an interrupt cannot produce a mixed capture/period/count structure.
- **R2-04 — Partial buzzer start:** If TIM15 channel 2 fails, channel 1 is stopped before the driver returns an error; stop remains idempotent.
- **R2-05 — Runtime service visibility:** BNO085 service/counter changes, UART service failures, and buzzer service failures latch `AtlasBoard.runtime_fault`; the main loop stops refreshing the watchdog after a startup or runtime fault.

#### Automated evidence

| Check | Result |
|---|---|
| Host C11 compile | Passed with MinGW-w64 GCC 13.1.0, `-Wall -Wextra -Werror` |
| Host protocol suite | Passed all assertions, including direct sensor register/command emulators, GNSS, BLE, RFD900x, LED, buzzer, and UART overflow |
| Arm GNU Debug clean build | Passed without compiler warnings; 121,412 bytes flash, 31,440 bytes DTCM |
| Arm GNU Release clean build | Passed without compiler warnings; 59,908 bytes flash, 31,440 bytes DTCM |
| Project source membership | All 14 `App/Src/*.c` units are present in CMake and IAR; all four pinned CEVA `.c` units are present in both |
| IAR project structure | `EWARM/Atlas.ewp` parses as XML and includes the required source/include paths |
| Dynamic/unsafe API scan | No project-owned `malloc`, `calloc`, `realloc`, `free`, `HAL_MAX_DELAY`, `sprintf`, `strcpy`, or `strcat` use found |
| Compiler stack-frame files | Largest observed project-owned single frame: 568 bytes in `AtlasGnss_SendUbx`; GNU linker reserves 16 KiB stack and zero heap |

The stack-frame inspection is not a whole-program call-chain or interrupt-nesting proof. It is evidence for targeted review, not a worst-case stack guarantee.

#### Design observations

- UART receive paths are allocation-free single-producer/single-consumer rings. ISRs capture bytes/errors and restart reception; foreground code parses protocols.
- SPI chip-select scope covers complete transactions. No dynamic allocation is used by the Atlas application layer.
- Device waits, conversion polls, command transactions, and startup probes use explicit time bounds. The intentional infinite loops are the main foreground scheduler and generated fatal `Error_Handler()` fail-stop.
- Ordinary startup performs no RFD900x AT command, no BLE save, and no GNSS nonvolatile write.
- Configuration APIs separate volatile setup from explicit persistence and document the NVM side effect.

#### Residual hold points

- IAR Embedded Workbench was unavailable, so XML/source membership was checked but no IAR object or map was produced.
- There is no static whole-call-graph stack proof, measured worst-case execution time, scheduler deadline analysis, or hardware-in-the-loop run.
- Host HAL emulators prove software handling of defined transactions; they do not prove electrical timing, silicon behavior, clock accuracy, or recovery from every physical fault.
- Independent qualified review remains required by [Engineering and Collaboration Standards](../DEVELOPMENT.md), especially before output, watchdog, interrupt, or control behavior is released.

## Review 3

### Review 3 — Documentation, Onboarding, and Repository Hygiene

| Field | Value |
|---|---|
| Date | 2026-09-01 |
| Scope | New-collaborator path, claim/evidence consistency, module guides, code documentation, links, forbidden artifacts, and generated-output hygiene |
| Method | Read-through from a new collaborator's perspective plus repeatable repository checks |
| Outcome | Pass for repository/document consistency; external URLs and physical procedures require ongoing maintenance |

#### Questions applied

1. Can a new collaborator determine what Atlas is, what is implemented, what is unverified, where each API lives, and how to build/test without relying on oral history?
2. Does every fitted sensor, major communications module, and user-feedback output have a guide containing wiring, startup behavior, API contract, units/format, health interpretation, known limits, primary references, and bench acceptance?
3. Do documentation claims distinguish protocol-tested, target-built, bench-verified, and flight-qualified status?
4. Are project-owned firmware files headed by purpose/major-function indexes, and are functions documented with Doxygen data tags and important inline rationale?
5. Are raw KiCad sources, obsolete Atlas_Origins material, build products, machine-local paths, and broken local links absent from the deliverable?

#### Findings resolved in this baseline

- **R3-01 — Stale validation descriptions:** The validation ledger and sensor/output guides understated the expanded direct-register, command-flow, LED, and buzzer host tests. The matrix now names the exact tested behavior without claiming physical verification.
- **R3-02 — Stale memory figures:** Build documentation was synchronized to the final clean images: Debug 121,412 bytes flash / 31,440 bytes DTCM and Release 59,908 bytes flash / 31,440 bytes DTCM.
- **R3-03 — Header consistency:** The shared status files now use the same “Major functions” convention as other project-owned units, and the generated `main.c` user header lists its Atlas integration responsibilities.
- **R3-04 — Failure semantics documentation:** BLE response overflow and RFD900x echo-only identity/settings rejection are now stated in API comments, module health tables, tests, and status evidence.

#### Onboarding path reviewed

The intended sequence is [README](../../README.md) → [Project Status](../SYSTEMS.md) → [Engineering Standards](../DEVELOPMENT.md) → [Module Firmware Guides](../README.md#device-references) → [Firmware Architecture](../reference/RTOS.md) → [Building](../DEVELOPMENT.md) → [Bring-up](../SYSTEMS.md) → [Validation Status](../SYSTEMS.md).

The path was checked for consistent vocabulary, safety boundaries, source authority, build prerequisites, debugger entry points, module ownership, persistent side effects, and handoff to physical acceptance.

#### Repeatable checks

Run from the repository root:

```text
powershell -ExecutionPolicy Bypass -File Tests/repository/check_repository.ps1
```

The check resolves every local Markdown target, requires the core onboarding/review documents, verifies Doxygen file/major-function headers and `@brief`/`@param`/`@return` tags for `App/` definitions, and rejects raw KiCad source extensions, Atlas_Origins paths, target build artifacts outside excluded build directories, and related repository debris. It passed for this reviewed snapshot.

Additional pass-specific scans found no project-owned use of machine-local `C:\Users\...` links and no stale prior memory figures. Occurrences of “LoRa” remain only where the documentation explicitly corrects that misconception.

#### Deliverable policy confirmed

- No raw KiCad schematic/PCB/project file is included.
- No file or directory named for obsolete Atlas_Origins material is included.
- The revision-matched schematic PDF, BOM, and candidate manufacturing outputs remain clearly labeled; they are not presented as verified as-built provenance.
- Generated build directories, ELF/HEX/BIN/map/object/stack-usage files are not part of the copy set.
- The source tree, module guides, tests, standards, review evidence, and supported build membership are included together.

#### Residual hold points

- External manufacturer links were selected from primary sources, but upstream URLs can move and should be checked during release preparation.
- Documentation cannot validate the as-built board, radio region, module firmware, calibration, timing, or fault recovery; each module guide deliberately ends in a physical acceptance procedure.
- These records are self-review evidence. They do not replace independent human review, requirements traceability, or flight qualification.

## Review 4

### Review 4 — RTOS Architecture, Timing, and Safety Supervision

#### Review identity

- **Review performed:** 2026-09-01
- **Scope:** FreeRTOS selection/configuration, task graph, ownership boundaries, interrupt contract, timing/deadline logic, sensor freshness, and independent-watchdog policy
- **Method:** line-by-line design review, call-site searches, target symbol inspection, deterministic host-policy tests, and comparison against the locally installed STM32CubeH7 FreeRTOS source
- **Result:** pass after the corrections recorded below

This is a rigorous author self-review, not an independent qualified avionics, functional-safety, hardware, or flight-readiness review.

#### Reviewed invariants

1. Exactly one post-start task owns each driver and complete bus transaction.
2. Interrupts perform only bounded flag, capture, and UART-ring work and call no FreeRTOS API.
3. Every scheduler object and stack has static application storage; no heap implementation is linked.
4. The application receives coherent copies and submits bounded commands instead of touching hardware.
5. The watchdog is refreshed by one highest-priority task only after positive evidence of liveness, status, freshness, deadline, and stack health.
6. All time comparisons remain correct across the 32-bit millisecond counter rollover.
7. Deliberately long radio/BLE maintenance calls cannot disguise a task stall or defer freshness indefinitely.

#### Evidence examined

- FreeRTOS Kernel V10.6.2 common sources and Cortex-M7 r0p1 GNU/IAR ports under `ThirdParty/FreeRTOS-Kernel/`.
- SHA-256 comparison of all 36 copied vendor files (excluding the Atlas-authored local README) against `STM32Cube_FW_H7_V1.13.0/Middlewares/Third_Party/FreeRTOS/Source`; every file matched.
- `FreeRTOSConfig.h`: 1 kHz preemption, static-only allocation, FPU enabled, stack checks, priority 15 kernel exceptions, and maximum syscall priority 5.
- `main.c`, `stm32h7xx_it.c`, startup vector behavior, NVIC configuration, and the GNU/IAR port membership.
- All project-owned task, queue, mutex, stream, delay, driver, callback, and watchdog call sites.
- Host tests for ordinary and wrapped periodic/freshness calculations and every supervisor decision branch, including active/expired long operations.

#### Findings and corrections

| ID | Severity | Finding | Correction and disposition |
|---|---|---|---|
| R4-01 | High | A prior supervisor decision could resume IWDG refresh after a fault had already latched. | The first `AtlasRtosHealth.fault` now overrides every later policy result; feeding can never resume before reset. Closed. |
| R4-02 | High | BLE, GNSS, RFD, and BNO polling/retry paths could consume a full timeout without yielding, starving the control task despite preemption intent. | All project driver waits use `AtlasTime_DelayMs()`, which becomes `vTaskDelay()` after scheduler start; busy polling now yields at 1 ms intervals. Closed. |
| R4-03 | Medium | A receive caller could spend its timeout once acquiring the reader mutex and again waiting for stream data. | Reader serialization is nonblocking; only the stream receive consumes the caller's bounded wait. Closed. |
| R4-04 | High | The control heartbeat advanced even if no coherent snapshot/hook cycle completed, weakening stall detection. | The heartbeat now advances only after snapshot acquisition and hook return. Closed. |
| R4-05 | High | Allowing both supervisor and I/O task to write `AtlasBoard.runtime_fault` created an unsynchronized C data race. | Board runtime state is single-writer I/O-owned; supervisor-only faults stay in mutex-protected RTOS health. Closed. |
| R4-06 | High | Task heartbeats and successful status codes did not prove sensors continued producing data. A permanently deasserted DATA_READY line could leave stale values marked valid while IWDG was fed. | Added required-sensor validity/age supervision, wrap-safe timestamp checks, a two-second startup grace, `SENSOR_STALE`, and a latched offending-bit mask. Closed pending bench rate validation. |
| R4-07 | High | A valid long radio/BLE transition paused sampling, so freshness would fault before the reviewed transition deadline. The exception also failed when an I/O heartbeat happened to advance during the same supervisor window. | The policy recognizes any active, in-deadline maintenance operation independently of heartbeat change; it defers freshness only for that bounded interval while still requiring application progress and stack health. Closed. |
| R4-08 | High | Clearing the long-operation marker immediately on return created a race: the supervisor could inspect stale pre-maintenance samples before the I/O task replenished them. Repeated transitions could also defer freshness forever. | The I/O task publishes maintenance inhibit state, then exactly one 1,200 ms recovery window. A second long transition is rejected during recovery; I/O liveness and error statuses remain enforced. Closed pending traffic/overflow bench tests. |
| R4-09 | High | A long call could exceed its deadline and return between 100 ms supervisor checks, escaping `IO_DEADLINE`. | The I/O task rechecks the saved deadline on return and latches the same fault before clearing busy state. Closed. |
| R4-10 | High | The 100 Hz control hook could overrun every 10 ms period yet keep changing its 100 ms heartbeat. | The complete snapshot-copy-plus-hook duration now latches `APPLICATION_DEADLINE` at 10 ms and records misses. Closed pending fine-grained bench timing. |
| R4-11 | Medium | Assertion/stack-overflow diagnostics were written before interrupts were disabled, leaving a narrow opportunity for one last supervisor refresh during partial capture. | Both fatal hooks disable interrupts before writing fault context. Closed. |

#### Interrupt and priority conclusion

The project requires `NVIC_PRIORITYGROUP_4`. SysTick and PendSV run at numerical priority 15; the maximum FreeRTOS syscall priority is 5. Existing priority 0–4 callbacks only set flags/counters or copy capture bytes and call no `...FromISR()` API, so they are legal above the kernel masking threshold. UART interrupt priorities are 6 and also call no RTOS API. Any future ISR-to-RTOS call requires a new priority audit.

The project-owned SysTick wrapper advances the HAL millisecond tick and calls the kernel tick only after scheduling starts. SVC and PendSV bodies come from the selected FreeRTOS port, avoiding duplicate handlers.

#### Open verification risks

- No assembled Atlas board was available in this review. Sensor rates, bus latency, UART/SHTP backlog recovery, interrupt loading, control jitter, and fault-reset behavior remain unmeasured.
- IWDG timing is derived from generated prescaler/reload settings and the nominal LSI frequency; oscillator tolerance and the real reset interval must be measured on each supported hardware revision.
- Radio/BLE mode transitions are explicitly maintenance-only. The application must inhibit control while `maintenance_active` or `sensor_recovery_active` is true.
- The 64-word live stack threshold and static stack allocations are conservative starting values, not proven worst-case margins.
- Fault context is not retained across reset; reset-cause/crash persistence remains future work.

#### Conclusion

The RTOS design is internally coherent and fail-closed at source/policy level after correction of the findings above. It is suitable as an integration foundation, but it is not yet hardware- or flight-validated. Review 5 separately verifies implementation/build evidence; Review 6 audits documentation and repository readiness.

## Review 5

### Review 5 — RTOS Implementation, Concurrency, Build, and Memory

#### Review identity

- **Review performed:** 2026-09-01
- **Scope:** project-owned RTOS implementation, task/ISR concurrency, queues and streams, fault paths, static memory, source membership, host tests, Arm builds, and linked-image symbols
- **Method:** fresh line-by-line source pass, lock/owner and preemption analysis, bounded-loop search, strict host tests, clean Debug/Release Arm GNU builds, GCC static analysis, linker-symbol/disassembly inspection, compiler stack-usage review, IAR XML/path inspection, and vendor-file hashing
- **Result:** pass at source/build level after the corrections below; IAR compilation and physical execution remain pending

This is a rigorous author self-review, not an independent qualified reviewer or hardware acceptance test.

#### Questions applied

1. Can any task, callback, or hook concurrently enter a driver or split a bus/module transaction?
2. Can a queue, mutex, stream, parser, retry, or interrupt-driven snapshot block or retry without a fixed bound?
3. Can any ordering window make the supervisor accept stale data, report a false stall, or resume watchdog refresh after a fault?
4. Are all scheduler resources fixed-size, correctly aligned/provisioned, and represented in both supported build systems?
5. Does the linked image contain exactly one exception implementation, one watchdog refresh call site, and no heap allocator?
6. Are stack allocations defensible from compiler evidence and guarded by live high-water supervision?
7. Are test/build claims limited to what the available toolchains and hardware actually prove?

#### Findings and corrections

| ID | Severity | Finding | Correction and disposition |
|---|---|---|---|
| R5-01 | High | A queued LED, buzzer, radio, or BLE request could otherwise reach hardware after startup/service/sampling or supervisor health had already failed. | The I/O owner checks running state, the monotonic RTOS fault, and all three aggregate statuses after dequeue. A rejected request completes with `ATLAS_ERROR_STATE` and does not call a driver. Closed; an operation already in progress remains bounded by its reviewed call/deadline contract. |
| R5-02 | High | At long-operation completion, clearing `io_busy` before publishing sensor recovery left a preemption window in which the supervisor could see neither a maintenance exception nor a fresh I/O heartbeat and diagnose a false stall/stale condition. | Recovery state is now published first. Completion advances the I/O heartbeat in the same health-mutex section that clears the busy gate, so every supervisor observation sees a valid side of the handoff. Closed pending bench transition stress. |
| R5-03 | Medium | The implementation and README claimed every task stack margin was supervised, but the static FreeRTOS idle task was covered only by overflow checking. | Enabled idle-task-handle access, added its high-water field to policy/health, and require the same 64-word minimum as the three Atlas tasks. Added the low-idle-stack host-policy case. Closed pending live high-water measurement. |
| R5-04 | Medium | The GNSS PPS coherence reader used an unbounded retry loop. Normal 1 Hz input made starvation implausible, but a noisy capture input violated the repository’s bounded-loop rule. | Limited the lock-free copy to three attempts and fail closed for that publication; the next I/O cycle retries naturally. PPS is not a watchdog-required sensor. Closed. |
| R5-05 | Medium | A redundant request to enter a module mode already active could unnecessarily open a long-operation/recovery interval and defer freshness. | Long-operation deadlines and recovery are now opened only for an actual BLE/RFD state transition; already-satisfied requests use the driver’s immediate idempotent path. Closed. |
| R5-06 | Medium | A long transition could return after its deadline between supervisor periods, and fatal diagnostic writes could be preempted before watchdog feeding stopped. | The I/O task checks the saved deadline again on return. Assertion and stack-overflow hooks disable interrupts before recording available context. Closed; also traced in [Review 4](REVIEW_HISTORY.md#review-4). |
| R5-07 | Low | Build parity and static-allocation rules depended on manual inspection alone. | The repository checker now rejects heap implementations, direct App-driver `HAL_Delay()`, and unreviewed `...FromISR()` calls; requires RTOS documents/files; verifies all App sources and kernel/port inputs in CMake/IAR; rejects cross-selected ports; parses the IAR XML; and resolves every referenced IAR file. Closed. |

#### Build and test evidence

- Host suite: all deterministic protocol/math and RTOS-policy checks pass under MinGW-w64 GCC 13.1.0 as C11 with `-Wall -Wextra -Werror`.
- Arm GNU 14.3.1 Debug: complete image compiles and links without warnings; 146,344 bytes flash and 51,976 bytes DTCM in the reviewed build.
- Arm GNU 14.3.1 Release: complete image compiles and links without warnings; 74,064 bytes flash and 51,976 bytes DTCM in the reviewed build.
- Strict project scope: all 17 `App/Src` units plus `main.c` and `stm32h7xx_it.c` pass `-Wall -Wextra -Werror` and GCC `-fanalyzer`. The three new RTOS units also pass `-Wshadow -Wformat=2 -Wdouble-promotion` as errors.
- The normal full-image `-Wall` build is clean. A broader extra-warning experiment reports findings in unchanged generated/vendor headers and USB/FatFs sources; those files are intentionally outside the stricter project-owned claim.
- Linked Release symbols contain exactly one `SVC_Handler`, `PendSV_Handler`, `SysTick_Handler`, and `xPortSysTickHandler`. Disassembly resolves the image’s sole call to `HAL_IWDG_Refresh()` to `atlas_rtos_supervisor_task`.
- No `malloc`, `free`, `pvPortMalloc`, or `vPortFree` symbol is linked, and no `heap_*.c` exists in the vendored kernel subset.
- Release disassembly retains a call from `atlas_rtos_application_task` to the weak `AtlasRtos_ApplicationStep`, so a strong application override is not optimized away.
- All 17 App sources are present in CMake and IAR. The IAR project XML parses and all 84 referenced file paths exist; the compiler was unavailable, so this is not an IAR build claim.
- SHA-256 comparison against the local STM32CubeH7 1.13.0 installation found all 36 copied FreeRTOS vendor files identical; the Atlas-authored README is excluded from that count.

#### Memory and stack review

All tasks, stacks, queue storage, mutex control blocks, and stream-buffer storage are application-static. The stream arrays provide 1,025 physical bytes each to the FreeRTOS ring implementation, yielding the documented 1,024-byte usable capacity.

Debug compiler direct-frame output reports:

| Task entry | Direct frame | Static stack | Interpretation |
|---|---:|---:|---|
| `atlas_rtos_io_task` | 40 bytes | 8,192 bytes | Deep driver callees dominate; direct size alone is not a call-depth bound. |
| `atlas_rtos_application_task` | 632 bytes | 4,096 bytes | The future control-hook call tree must fit inside the same task stack. |
| `atlas_rtos_supervisor_task` | 696 bytes | 2,048 bytes | Includes four high-water queries and coherent policy inputs. |
| FreeRTOS idle | kernel-dependent | 1,024 bytes | Performs no Atlas hook; live margin is now supervised. |

Notable project callee frames include 568 bytes for `AtlasGnss_SendUbx`, 392 bytes for `AtlasMs5611_Compensate`, and 328 bytes for `AtlasBle_Command`. These figures are compiler-local frames, not whole-call-chain proofs. The 64-word supervisor threshold and the initial allocations remain hypotheses until live high-water marks are retained under worst-case traffic and fault paths.

#### Residual limits

- No IAR compiler was available; only project structure, options, XML, and referenced files were checked.
- Address/undefined-behavior sanitizers were unavailable in the installed MinGW toolchain, so no sanitizer result is claimed.
- No assembled Atlas board was available. Bus electrical behavior, module firmware compatibility, throughput/backlog behavior, timing/jitter, live stack margins, and watchdog reset timing remain governed by [Module bring-up and acceptance](../SYSTEMS.md).
- Source/build review cannot prove sensor accuracy, RF delivery, BLE pairing, GNSS fix quality, or safe flight behavior.

#### Conclusion

The reviewed RTOS implementation is internally consistent, statically provisioned, warning-clean in the stated scopes, and fail-closed at its software supervision boundaries after the corrections above. It is a strong integration baseline, not hardware or flight qualification. Review 6 separately audits documentation, onboarding, links, and repository hygiene.

## Review 6

### Review 6 — RTOS Documentation, Onboarding, and Repository Hygiene

#### Review identity

- **Review performed:** 2026-09-01
- **Scope:** collaborator entry path, RTOS/API contract, module guides, build/validation claims, function documentation, cross-links, source membership, third-party provenance, and excluded-artifact policy
- **Method:** fresh reader walkthrough from README to first control-hook integration; source-to-document comparison; terminology/number search; module-guide coverage matrix; local-link and Doxygen-tag automation; CMake/IAR parity check; and repository artifact scan
- **Result:** pass after the corrections recorded below

This is the third RTOS-specific author self-review and the sixth sequential repository review. It is not an independent reviewer or physical acceptance.

#### Reader questions applied

1. Can a new collaborator find the current status, safety boundary, build/test path, RTOS ownership rules, and first application integration point without relying on oral history?
2. Does each fitted sensor, communications module, and feedback output explain both its direct driver and the supported post-scheduler interface?
3. Are time domains, validity, freshness, maintenance, asynchronous completion, overflow, persistence, and peer/link limitations stated without ambiguity?
4. Do build sizes, toolchain status, test scope, and validation labels match the final evidence exactly?
5. Do all project functions carry the requested file header and Doxygen `@brief`, `@param`, and `@return` tags?
6. Can automation prevent raw KiCad sources, obsolete Atlas_Origins material, generated binaries, RTOS heap code, or build-membership drift from entering unnoticed?

#### Findings and corrections

| ID | Severity | Finding | Correction and disposition |
|---|---|---|---|
| R6-01 | Medium | `atlas_time.h` advertised an `AtlasTime_MillisecondsToTicks()` helper that did not exist. | Removed the phantom function from the major-functions header; the public timing surface now exactly matches the implementation. Closed. |
| R6-02 | Medium | Several current guides still described watchdog and service behavior as a “main loop” or generic foreground loop after RTOS integration. | Current BNO085, buzzer, status, and bring-up language now names `AtlasWatchdog` or `AtlasIO`. The historical Review 2 record retains its original wording with an explicit supersession note instead of being silently rewritten. Closed. |
| R6-03 | High | The BNO085 guide could lead an application author to compare the SH-2 report timestamp directly with the MCU HAL clock. | The RTOS section now requires the matching `bno_*_received_at_ms` field for MCU-clock age and treats the SH-2 timestamp/accuracy as separate report-quality metadata. Closed. |
| R6-04 | High | The BLE/RFD module pages described queued mode transitions but did not explicitly repeat the control inhibit across both maintenance and sensor recovery. | Both guides now require control inhibition for `maintenance_active` and `sensor_recovery_active`; the architecture document explains the ordered recovery-publication/heartbeat/busy-gate handoff. Closed pending bench stress. |
| R6-05 | Medium | Validation prose could be read as if the complete per-sensor stale-bit mapping were host-executed. | The ledger, project status, and build guide now distinguish host-tested wrap-safe age/supervisor decisions from the source-reviewed per-sensor required-bit/age mapping. Closed. |
| R6-06 | Medium | The review index and repository checker still covered only the original three communication reviews and did not enforce the RTOS integration contract. | Indexed all six passes. The checker now requires Reviews 4–6 and the RTOS files, verifies matching GNU/IAR kernel ports and every App source, parses/resolves the IAR project, and guards timing/ISR/static-allocation rules. Closed. |
| R6-07 | Low | Build-size evidence became stale after the final concurrency, idle-stack, and PPS-bound corrections. | Replaced all prior figures with clean final desktop-source values: 146,344-byte Debug flash, 74,064-byte Release flash, and 51,976-byte DTCM for both. Closed. |
| R6-08 | Low | The excluded-artifact check covered principal KiCad project extensions but not symbol, footprint, design-rule, job-set, library-table, or `.pretty` inputs. | Expanded the raw-KiCad extension/name/directory policy while continuing to allow reviewed exports and candidate manufacturing outputs. Closed. |

#### Documentation coverage

| Need | Authoritative location | Review result |
|---|---|---|
| First orientation and safety boundary | [Repository README](../../README.md) | Current RTOS capability and non-claims are visible before build instructions. |
| Coding, concurrency, review, and release rules | [Engineering standards](../DEVELOPMENT.md) | Static ownership, deadlines, freshness, interrupts, watchdog, evidence, and review gates are explicit. |
| Task graph and application API | [RTOS architecture](../reference/RTOS.md) | Tasks, priorities, rates, snapshots, commands, streams, maintenance, interrupts, memory, faults, and bench acceptance are complete. |
| Full firmware layering/failure model | [Firmware architecture](../reference/RTOS.md) | Generated/project/vendor boundaries and failure consequences agree with source. |
| Reproducible tool/test path | [Building](../DEVELOPMENT.md) | Tool versions, clean sizes, commands, output checks, IAR limitation, and troubleshooting are current. |
| Physical acceptance | [Bring-up](../SYSTEMS.md) | Safe setup, all modules, RTOS load/fault cases, and retained evidence template are present. |
| Claim vocabulary and matrix | [Validation status](../SYSTEMS.md) | Implemented/protocol-tested/target-built/bench-verified/flight-qualified remain distinct. |
| Current boundary and backlog | [Project status](../SYSTEMS.md) | Implemented, pending physical work, and deliberately absent control/safety functions are separated. |
| Dependencies and update discipline | [Third-party provenance](../reference/PROVENANCE.md) | CEVA and FreeRTOS source/version/license/update procedures are recorded. |

All ten device/output guides—ADXL375, LSM6DSV16B, MMC5983MA, MS5611, BNO085, GNSS, BLE, RFD900x, LED, and buzzer—contain a major-functions index, conservative validation state, explicit RTOS access/ownership section, board/protocol contract, health/fault interpretation, known limits, primary references, and repeatable bench acceptance. Direct examples are labeled pre-scheduler/isolated where post-start driver access would violate ownership.

#### Automated hygiene evidence

`Tests/repository/check_repository.ps1` passes for the reviewed tree and verifies:

- every local Markdown link resolves;
- all required entry, architecture, module-index, validation, RTOS, and six review documents exist;
- all project-owned App files have a Doxygen file/major-functions header;
- every recognized App function definition has an adjacent `@brief`, every parameter has `@param`, and non-void functions have `@return`;
- no raw KiCad source, Atlas_Origins path, build product, or FreeRTOS `heap_*.c` appears outside excluded build directories;
- no App runtime driver bypasses `AtlasTime_DelayMs()` with direct `HAL_Delay()`;
- no App/Core peripheral path calls an RTOS `...FromISR()` API without forcing a new priority review;
- all 17 App sources are in CMake and IAR;
- both builds contain the required common kernel sources, definition, include paths, and their matching Cortex-M7 r0p1 port, with no cross-selected port;
- the IAR XML parses and all 84 referenced file paths exist.

#### Residual limits

- The checker validates local Markdown targets but does not fetch or archive external manufacturer/FreeRTOS URLs.
- Documentation cannot validate electrical wiring, exact fitted part/firmware revision, real-time margins, or module communication. Those remain physical acceptance work.
- The records are sequential self-reviews, not the independent qualified approvals required by [Engineering standards](../DEVELOPMENT.md) for safety-relevant release.
- The project still has no selected project-level license; the README warns collaborators not to infer reuse rights.

#### Conclusion

A new collaborator now has a coherent, source-matched path from repository purpose and safety limits through RTOS application integration, module operation, build/test evidence, and physical acceptance. Automated checks cover the most likely documentation, source-membership, static-allocation, and artifact-policy regressions. The repository is ready for collaborative implementation work at the documented development maturity; it is not yet bench-verified or flight-qualified.

## Full review before corrections

The following is the complete pre-correction review published on 2026-09-01. Its failures and no-implementation statements describe that earlier snapshot, **not the current firmware**. Headings and links are rebased for this archive; the retired SD test-wrapper reference is marked. Current dispositions and the subsequent three correction-review passes are in [the current report](../REVIEW_REPORT.md).

## Baseline review: Complete codebase and documentation review

### Baseline review: Decision

**All-systems bring-up: not accepted.** The unchanged firmware cannot sustain an all-healthy startup and does not implement every requested board service. The documentation is consolidated around [Quick start](../QUICK_START.md), [Systems](../SYSTEMS.md), and [Development](../DEVELOPMENT.md); the findings below remain open unless explicitly marked as a documentation correction.

- Review date: **2026-09-01**.
- Firmware baseline: **`0dbc245` — Implementing RTOS**.
- This change edits documentation/repository checks and adds host-only diagnostic acceptance probes. It does **not** repair firmware, change hardware artifacts, flash a device, access a card, transmit RF, commission NVM, or actuate outputs.
- Owner clarification: J9's connector labeled “LoRa” will use **RFD900x**. The firmware radio target is correct; modem settings and peer operation are still unverified.
- These are **three sequential author self-reviews**, not three independent reviewers or a safety release approval. Earlier conclusions are retained only in the [historical archive](../archive/REVIEW_HISTORY.md).

### Baseline review: Scope and method

The review traversed all 17 project-owned App implementations/headers; generated startup, clocks, MSP, IRQs and fault paths; FatFs/BSP/disk configuration; USB initialization/CDC/PCD/descriptors; GNU/IAR source membership, startup and active memory layouts; existing host tests/mocks; repository checks; and all project-authored guides/reviews.

Vendor review covered the interfaces and selected implementation paths used to assess integration (notably HAL timer state, SD initialization/DMA, kernel tick/port behavior), provenance, and compiled build coverage. It was **not** a line-by-line audit or certification of the entire HAL, CMSIS, FreeRTOS, CEVA, FatFs or USB vendor implementation, nor a current vulnerability audit.

All ten schematic PDF pages were visually inspected, with focused checks of buses, USB, indicators, power and output paths. Manufacturing file hashes were checked, not fabrication correctness, PCB routing, BOM/CPL alignment, fitted substitutions or assembled electrical behavior. No physical board or external module was exercised.

### Baseline review: Three review passes

| Pass | Distinct work | Outcome |
|---|---|---|
| 1 — source, startup and hardware contracts | Trace boot → driver → HAL; all peripheral call sites; bus/IRQ ownership; schematic power/pin cross-check; installed capability vs active service | Found shared TIM2 startup failure, SD/USB/service gaps, DMA placement conflicts and incorrect hardware/LED assumptions |
| 2 — reproducible behavior and build evidence | Clean GNU Debug/Release; existing host suite; strict target analysis; linker/symbol/stack inspection; new positive-control + adverse-case probes | Builds/protocol tests pass while six integration findings reproduce; analyzer and mock limits recorded rather than promoted to hardware success |
| 3 — documentation, tests and preservation | Consolidated reader walkthrough; module/API/claim cross-check; probe review; local links/anchors and artifact/membership checks; compare firmware/hardware against baseline | Current entry path and finding status made explicit; historical pass claims superseded; final check results recorded below |

### Baseline review: Priority summary

P1 means a bring-up/operational blocker or serious latent integration risk. P2 means a resilience/real-time guarantee gap that must be resolved before relying on that behavior. “Latent” means the service is not currently started; it is not a defect observed on physical hardware.

| ID | Priority | Finding | State |
|---|---|---|---|
| [R01](#baseline-review-r01-gnss-startup-restarts-an-already-running-timer) | P1 | GNSS restarts TIM2 already started by BNO085 | Reproduced; firmware unchanged |
| [R02](#baseline-review-r02-rtos-waits-do-not-guarantee-minimum-device-delays) | P1 | Tick waits can undershoot physical minimum delays | Reproduced at timing boundary; firmware unchanged |
| [R03](#baseline-review-r03-sd-lazy-initialization-uses-an-unconfigured-handle) | P1 | SD lazy initialization passes an unconfigured HAL handle | Reproduced; latent until mount/init |
| [R04](#baseline-review-r04-sd-read-completion-can-be-erased) | P1 | SD read completion flag reset occurs after DMA launch | Reproduced; latent |
| [R05](#baseline-review-r05-sd-timeouts-do-not-establish-buffer-release) | P1 | SD timeout lacks guaranteed DMA quiescence and bounded task-friendly completion | Reproduced at adapter boundary; latent |
| [R06](#baseline-review-r06-default-memory-is-not-sdmmc1-or-dma1-accessible) | P1 | Default DTCM layout is invalid for direct SDMMC1/DMA1 buffers | Source/map/manual confirmed; latent |
| [R07](#baseline-review-r07-usb-is-not-a-complete-or-started-cdc-service) | P1 | USB not started; RX/control/TX lifecycle incomplete | Source confirmed; latent |
| [R08](#baseline-review-r08-gnss-parser-has-no-truncated-frame-age-limit) | P2 | Truncated frame can suppress later valid GNSS data | Reproduced; remains after R01 is fixed |
| [R09](#baseline-review-r09-hardware-labels-and-power-protection-claims) | P1 | Incorrect pyro protection claim and conflicting LED color mapping | Documentation corrected; physical mapping pending |
| [R10](#baseline-review-r10-deadline-checks-do-not-cover-release-lateness) | P2 | Timing checks do not prove scheduled response deadlines | Source confirmed; no physical timing acceptance |
| [R11](#baseline-review-r11-configured-peripherals-are-not-complete-services) | P1 | Missing services/commissioning prevent all-systems operation | Capability gap; no implementation added |

### Baseline review: R01: GNSS startup restarts an already-running timer

Sources: [board startup](../../App/Src/atlas_board.c), [BNO085 init](../../App/Src/atlas_bno085.c), [GNSS init](../../App/Src/atlas_gnss.c), [bundled HAL timer](../../Drivers/STM32H7xx_HAL_Driver/Src/stm32h7xx_hal_tim.c).

`AtlasBoard_Init()` passes the same TIM2 handle to BNO085 and then GNSS. BNO085 calls `HAL_TIM_Base_Start()`; the HAL changes the handle state from READY to BUSY. GNSS calls that function again, but this HAL rejects any state other than READY. GNSS returns `ATLAS_ERROR_IO` before its MON-VER poll and the RAM configuration is not ready.

The new stateful timer probe passes isolated GNSS startup, then reproduces the shared-running-timer failure with **zero MON-VER polls**. The old host stub always returned HAL_OK and did not run board/BNO startup, masking the conflict. The startup aggregate then prevents watchdog refresh; a sustained healthy system is not possible on this path.

Required correction: establish one owner/start point for TIM2 while preserving BNO085 time and GNSS capture. Do not stop/reset the shared clock merely to make the second call succeed. Acceptance needs actual board-order startup, one timer start, advancing BNO timestamps, GNSS identity/configuration and PPS.

### Baseline review: R02: RTOS waits do not guarantee minimum device delays

Sources: [time helper](../../App/Src/atlas_time.c), [MS5611 conversion](../../App/Src/atlas_ms5611.c), [BLE transition](../../App/Src/atlas_ble.c). Primary references: [FreeRTOS tick resolution](https://www.freertos.org/Documentation/02-Kernel/05-RTOS-implementation-tutorial/02-Building-blocks/11-Tick-Resolution), [TE MS5611 datasheet](https://www.te.com/commerce/DocumentDelivery/DDEController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), [u-blox data-mode timing, section 5.1.4](https://content.u-blox.com/sites/default/files/u-connectXpress-ATCommands-Manual_UBX-14044127.pdf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).

The running-scheduler branch converts milliseconds to ticks and calls `vTaskDelay()` without accounting for phase within the current tick. At 1 kHz, N ticks can wait only just over N−1 milliseconds. The header's “at least” promise is false.

For OSR1024, MS5611 requests 3 ms while the conversion maximum is 2.28 ms. The probe models a legal 2.001 ms wake; actual bus/CPU overhead is not a guaranteed replacement for the missing delay. The datasheet warns that early ADC access can return zero and disturb conversion. Other OSR waits also need correction. BLE requests a minimum 50 ms ATO1-to-payload gap but can obtain 49.001 ms; explicit MMC5983MA SET/RESET waits and other post-start minimum delays need the same audit.

Required correction: a minimum-elapsed-time contract with overflow-safe conversion and scheduler-phase allowance, followed by protocol-specific timing tests. Verify physical minimum delay separately from maximum I/O latency. This probe is a legal scheduling model, not a measured target waveform or a claim that every conversion fails.

### Baseline review: R03: SD lazy initialization uses an unconfigured handle

Sources: [main](../../Core/Src/main.c), [FatFs registration](../../FATFS/App/fatfs.c), [BSP](../../FATFS/Target/bsp_driver_sd.c), [HAL SD](../../Drivers/STM32H7xx_HAL_Driver/Src/stm32h7xx_hal_sd.c).

`main()` calls `MX_FATFS_Init()` but never `MX_SDMMC1_SD_Init()`, the helper that assigns `hsd1.Instance` and its configuration. FatFs initialization only links the disk driver. On a later mount, `BSP_SD_Init()` calls `HAL_SD_Init(&hsd1)` while that global handle is still unconfigured.

The mock observes a NULL peripheral instance at the HAL boundary. The real HAL assumes a valid instance and can reach invalid register access; its disabled parameter assertions are not a recovery path. The source comment promising valid lazy initialization is therefore misleading.

Required correction: define the complete SDMMC1 configuration/card lifecycle before FatFs can initialize it, without making absent media fatal to unrelated startup. A successful `f_mount()` path must be tested; adding the mount alone is not a fix.

### Baseline review: R04: SD read completion can be erased

Source: `SD_read()` in [sd_diskio.c](../../FATFS/Target/sd_diskio.c).

The adapter starts DMA, then clears `ReadStatus`. If completion interrupts after DMA is enabled but before that store, the callback's completion is erased and the reader waits until timeout. The write path correctly clears its flag before launching.

The probe delivers completion at the launch boundary to model that allowed interleaving: immediate read completion returns `RES_ERROR` after about 30 seconds of modeled time, while delayed read and immediate write controls pass.

Required correction: initialize completion state before launch and use an operation-scoped completion protocol that also handles error, cancellation, stale callbacks and serialization.

### Baseline review: R05: SD timeouts do not establish buffer release

Sources: [disk adapter](../../FATFS/Target/sd_diskio.c), [BSP callbacks](../../FATFS/Target/bsp_driver_sd.c).

Read/write timeout paths return without requesting/verifying abort or otherwise proving DMA has released the caller's buffer. In the stalled-transfer model, the function returns an error while DMA still owns it. This does not claim every HAL error leaves DMA active; it shows the adapter has no guaranteed ownership handoff on its timeout path.

It also spins on completion/card state, with 30-second timeout phases and no task-friendly wait. Moving that code into `AtlasIO` could starve lower-priority control and prevent required progress. Error/abort callbacks do not supply a complete wake/result path.

Required correction: one storage owner; bounded IRQ-to-task completion; explicit success/error/abort states; verified quiescence before buffer reuse; media-removal handling and stale-callback tests. FatFs `_FS_REENTRANT=0`; `_FS_LOCK=2` is not an RTOS mutex.

### Baseline review: R06: Default memory is not SDMMC1 or DMA1 accessible

Sources: [GNU linker](../../STM32H743XX_FLASH.ld), [active IAR linker](../../EWARM/stm32h743xx_flash.icf), [disk adapter](../../FATFS/Target/sd_diskio.c). Primary references: [ST AN4891, DTCM access](https://www.st.com/resource/en/application_note/dm00306681.pdf), [ST AN5200, SDMMC1 access table](https://www.st.com/resource/en/application_note/an5200-getting-started-with-stm32h7-mcus-sdmmc-host-controller-stmicroelectronics.pdf).

Ordinary writable data and static task stacks are in DTCM at `0x20000000`; current target maps allocate no ordinary data in the other SRAM regions. DTCM is directly accessible to CPU/MDMA, not SDMMC1 IDMA or DMA1. No reachable SD bounce buffer, explicit DMA section, or MDMA bridge is implemented. The adapter directly casts caller buffers; its optional scratch-buffer path is disabled.

Required correction: select memory reachable by the specific DMA master (SDMMC1's supported AXI path, not an arbitrary “SRAM” region), preserve alignment/ownership, update both linkers and startup initialization as necessary, and validate addresses in maps plus actual transfers. ADC acquisition using DMA1 needs its own reachable buffers. **D-cache is not enabled today**; cache coherency is an additional future design obligation, not the active cause reported here.

### Baseline review: R07: USB is not a complete or started CDC service

Sources: [USB device](../../USB_DEVICE/App/usb_device.c), [CDC interface](../../USB_DEVICE/App/usbd_cdc_if.c), [PCD setup](../../USB_DEVICE/Target/usbd_conf.c), [GPIO callback routing](../../App/Src/atlas_board.c).

`MX_USB_DEVICE_Init()` has no caller, so ordinary boot does not enumerate. Merely adding that call would still leave `CDC_Receive_FS()` discarding incoming bytes, control requests (including GET_LINE_CODING) unimplemented, and no task-owned command/console service.

`CDC_Transmit_FS()` dereferences `pClassData` without a configured-class check; before enumeration or after teardown it can be NULL. It also hands the caller's buffer to an asynchronous transfer without a project-level lifetime/serialization contract.

PCD VBUS sensing is disabled. PA9's external VBUS divider is configured as an input/EXTI, but application connection gating is absent. The externally powered design needs a reviewed connect/disconnect policy, not unconditional pull-up exposure. The schematic's D−/D+ routing was rechecked and **is not reported as swapped**.

Required correction: complete the initialization/VBUS lifecycle, valid CDC control behavior, bounded RX queue and task processing, configured-state/TX-busy checks, retained TX ownership and disconnect recovery. USB behavior was source-reviewed, not host- or hardware-executed in this review.

### Baseline review: R08: GNSS parser has no truncated-frame age limit

Source: the length/discard states in [atlas_gnss.c](../../App/Src/atlas_gnss.c).

An oversized UBX length enters discard mode for the entire declared payload plus checksum. There is no inter-byte/frame timeout. A header declaring 65535 bytes followed by a long gap and a valid NAV-PVT can leave that valid frame treated as discarded payload.

The probe waits 5 seconds of modeled time and injects a valid NAV-PVT after the truncated header. No navigation sample is published and `discard_remaining` is still 65437. Buffer writes are bounded; this is a recovery/availability defect, not a demonstrated memory overflow.

Required correction: a bounded resynchronization policy for truncation, overflow and prolonged gaps, with fragmented valid frames, noise, embedded sync bytes and tick-wrap tests. R01 currently masks normal operation; R08 remains after startup is corrected.

### Baseline review: R09: Hardware labels and power-protection claims

Source: [schematic PDF](../../hardware/Atlas-schematic-rev-0.1.pdf); consolidated [hardware evidence](../reference/HARDWARE.md).

1. **Pyro feed:** J5 links `VIN_RAW` to `PYRO_VBAT_ARMED`, bypassing TPS16850 U11. The former hardware overview incorrectly included “shared input protection” among constraints on pyro current. That claim is removed; no independent channel limiter is shown. The physical arm link remains open for ordinary development.
2. **LED mapping:** software `LED_G`/PB7 reaches D5 pin 4 (B), and `LED_B`/PD14 reaches pin 3 (G), according to the schematic. Guides now distinguish logical masks from emitted colors. Exact fitted-part/as-built verification is required before remapping firmware or interpreting colors.
3. **Radio label:** the owner explicitly confirmed RFD900x on J9. The legacy “LoRa” label is now explained, not treated as a protocol-selection defect.

Disposition: incorrect documentation is corrected in this change. Neither the schematic nor hardware nor firmware was altered, and the LED discrepancy is not claimed physically resolved.

### Baseline review: R10: Deadline checks do not cover release lateness

Source: `atlas_rtos_application_task()`, `atlas_rtos_io_task()` and supervisor policy in [RTOS implementation](../../App/Src/atlas_rtos.c).

The application measures elapsed time starting **after** `vTaskDelayUntil()` returns. It catches a slow snapshot/hook cycle, but not a late task release caused by higher-priority I/O/interrupts. A task can start well after its scheduled deadline, finish quickly, and still advance its heartbeat within the 100 ms supervisor interval. For example, stream commands permit a 50 ms synchronous UART timeout in priority-4 `AtlasIO`; a blocked BLE transmit can delay priority-3 control without that wait being included in the control cycle's elapsed-time check.

`io_deadline_misses` counts cycles exceeding 20 ms without independently latching a fault. Synchronous sensor conversions/maintenance can also reduce delivery rates; device ODRs are not lossless acquisition guarantees.

Required correction: define and measure release jitter, complete response deadlines, skipped-release/catch-up policy, queue latency and acceptable sensor sample loss. Decide which overruns are faults. Current documentation now calls the 100 Hz cadence nominal, not proven hard-real-time operation.

### Baseline review: R11: Configured peripherals are not complete services

Sources: [main](../../Core/Src/main.c), [RTOS command/snapshot API](../../App/Inc/atlas_rtos.h), [FatFs configuration](../../FATFS/Target/ffconf.h), and per-system sources linked in [Systems](../SYSTEMS.md).

- **SD:** no mount/open/write/logger, removal lifecycle or valid file-time service; card detection always reports present.
- **BLE/RFD900x:** identity/transport or configuration helpers are not a commissioned peer link. BLE ordinary boot does not activate the complete SPS path. General configuration is not exposed in the RTOS queue; persistent changes must remain deliberate. No project framing/security/reconnect layer exists.
- **ADC:** generated ten-channel ADC1 and two-channel ADC3 setup is not calibration, conversion start, sampled data, scaled rail/continuity telemetry or thresholds.
- **PWM/GPIO/expansion:** timers/pins/UART/I2C/SPI are configured, but actuator channels are not started and no complete task-owned control/client interface exists.
- **Pyro:** five low gate outputs only. No physical-arm interpretation, valid continuity acquisition, arming/firing state machine, independent pulse limit or qualified fault/lockout behavior.
- **RTC/power/ECC:** initialization and IRQ scaffolding do not implement wall-clock/file-time management, complete power/RAM fault monitoring, or retained reset/crash records.
- **Application:** the weak control hook is empty; no flight algorithm, logger, telemetry protocol or comprehensive output-safe-state controller exists.

These are explicit scope/capability gaps, not newly introduced regressions. The [readiness matrix and acceptance gates](../SYSTEMS.md) now make each visible. Implementing them requires separately reviewed service contracts and inert tests; this review did not add hazardous output behavior.

### Baseline review: Executable evidence

Tests used Arm GNU 14.3.1 (14.174), CMake 3.26.4 with MinGW Makefiles/GNU Make, host GCC 13.1.0 and PowerShell 7. The Ninja presets were inspected but not used for the fresh target builds; no IAR compiler/hardware was available.

| Check | Observed result | Boundary |
|---|---|---|
| Fresh complete GNU Debug | Pass; **146540 bytes flash, 51976 bytes DTCM** | Normal repository `-Wall` build, no compiler warnings |
| Fresh complete GNU Release | Pass; **74264 bytes flash, 51976 bytes DTCM** | Normal repository `-Wall` build, no compiler warnings |
| Strict target compile/analyzer, 17 App sources | Pass: `-O0 -Wall -Wextra -Werror -fanalyzer` | Actual object compilation, not syntax-only analysis |
| Main/IRQ strict analyzer | Reports deliberate terminal infinite loops | Not included in the zero-finding App claim; rerun allowing only that diagnostic to remain a warning |
| Existing host protocol suite | Pass, 15 test functions | Selected contracts under mocks, not full board/RTOS execution |
| Focused review probes | **Fail, exit 1; three groups / six finding IDs** | R01/R02/R03/R04/R05/R08 reproduced under boundary models |
| Kernel handlers / allocator symbols | One each of SVC, PendSV, SysTick and port tick; no linked malloc/sbrk/FreeRTOS heap allocator | GNU Debug symbol inspection; not runtime stack proof |
| Static stack frames | Largest reviewed App frame 696 bytes (supervisor), then 632 (application task), 568 (GNSS send) | Individual frames, not summed call-chain/ISR/FPU worst case |
| IAR | XML/member/port/linker inspection only | No binary or IAR size/timing claim |
| Vendor provenance | 31 kernel files match after newline normalization; 12 CEVA files byte-identical | Clean pinned CEVA checkout and installed CubeH7 package; no security certification |
| Manufacturing manifest | All 19 file hashes match | Preservation, not fabrication acceptance |
| Physical operation | **Not tested** | No sensor, radio, USB, SD, ADC, actuator or pyro bench claim |

Build sizes include current path-dependent strings such as assertion file names and are evidence for this snapshot/build environment, not immutable limits. Remaining SRAM regions are not used by ordinary data in these maps. Historical size values are retained only in the archive.

#### Baseline review: Reproduce the behavioral findings

From the repository root with host GCC on PATH:

```powershell
pwsh -NoProfile -File Tests/review/run_review_probes.ps1
```

Representative observed output:

```text
CONTROL PASS: zero and pre-scheduler timing
FAIL R02: requested 3 ms, earliest modeled wait 2001 us
FAIL R02: requested 50 ms, earliest modeled wait 49001 us
CONTROL PASS: isolated GNSS startup and clean NAV-PVT
FAIL R08: after 5 s and a valid NAV-PVT, discard_remaining=65437
FAIL R01: GNSS with shared running timer returned IO; MON-VER polls=0
FAIL R03: BSP passed an unconfigured SD peripheral handle to HAL_SD_Init
CONTROL PASS: delayed read completion and immediate write completion
FAIL R04: early read completion returned 1 after 30003 modeled ms
FAIL R05: timeout returned 1 with mock DMA still owning the caller buffer
REVIEW GAPS OPEN: 3 probe groups failed acceptance.
```

The [timing probe](../../Tests/review/test_timing.c) executes the real RTOS-aware helper against an earliest-legal-wake model. The [GNSS probe](../../Tests/review/test_gnss_integration.c) executes real GNSS/UART code with a stateful HAL timer stub and injected replies; it models BNO's already-started timer, not a complete BNO/board run. The [SD probe](../../Tests/review/test_sd_integration.c) executes real disk/BSP adapters with controlled HAL completion and ownership. Its then-current `Tests/review/sd_bsp_host.c` wrapper (retired after this baseline; recoverable from the pre-correction backup) adapted weak callback linkage for MinGW; callback injection is at the BSP/disk boundary, not a HAL IRQ-routing test.

Positive controls must continue passing. Exit 2 denotes a harness/build failure, not a reproduced firmware defect. The SD group suppresses pre-existing generated unused-parameter warnings only. Passing these probes after a future fix would still not prove electrical communication, real DMA reachability, full FreeRTOS behavior, or complete protocol resilience.

The R03 fixture deliberately models the current uninitialized `hsd1` at the BSP boundary. If a future fix moves ownership into board startup instead of the BSP, update the fixture only alongside a test proving that real startup prepares the handle before filesystem use. Do not weaken a test merely to remove its failure message.

#### Baseline review: Final documentation and preservation checks

All three review passes are complete. The following checks were performed on the consolidated work, with the host/probe/repository commands repeated after publication into the actual desktop repository:

| Check | Result |
|---|---|
| Reader path and guide count | One documentation hub; Quick start + Systems form the starting path. Project-authored guides reduced from **31 to 22**, retaining ten optional device references and one historical archive; vendor notices and the PR template are excluded from this count. |
| Repository checker | **Pass: 254 local links and 48 heading anchors**, required guides, App Doxygen tags, artifact policy and GNU/IAR membership. This is the documented Markdown subset, not a general parser or external-link check. |
| Checker negative controls | Exactly two intended failures for a missing file and heading; a duplicate-heading suffix resolves and nonexistent links inside both supported fence styles are ignored. The temporary fixture was removed. |
| Documentation/source consistency | 69 documented Atlas function identifiers matched source/header text. The complete non-actuating Development example target-compiled with C11, `-Wall -Wextra -Werror`; name matching alone is not API execution coverage. |
| Published host/probe rerun | Existing host suite passes; review probes still return **exit 1** for R01/R02/R03/R04/R05/R08, with positive controls passing. A missing-compiler harness control correctly returns **exit 2**. |
| Publication preservation | All **311 baseline files outside the planned documentation/checker edits are byte-identical** to their pre-publication checkout SHA-256 values, including firmware, existing host tests, vendor code, build definitions, linkers and hardware exports. |
| Retired paths and recovery | 18 obsolete/duplicate guide paths were retired and ten device guides relocated. Six earlier reviews remain in the historical archive; the complete originals are recoverable from `0dbc245` and an independently retained baseline ZIP. |

The staging copy came from Git's archive and differs from the checkout in line endings for some unchanged files. That normalization was checked explicitly; those firmware/build/vendor files were **not copied back**. Only the scoped documentation, repository checker, PR template, hardware README links and new host-only review probes were published. No generated build products, raw KiCad designs or obsolete origin material were added.

### Baseline review: Recommended closure order

1. Fix R01/R02 with real shared-resource/timing contracts and keep the new acceptance probes red until behavior actually meets their assertions.
2. Fix GNSS resynchronization and establish release-deadline/sampling requirements (R08/R10); bench-accept sensors, clocks and RTOS under concurrent traffic.
3. Implement SD as a complete owned service, addressing R03–R06 before allowing a filesystem caller; implement USB lifecycle and transport (R07).
4. Commission the exact RFD900x/BLE modules deliberately, then add framing, security, reconnect and load tests.
5. Add ADC, GPIO, expansion and actuator services under explicit contracts. Pyro functionality requires a separate qualified safety design and approval, not a bring-up shortcut.
6. Retain physical evidence for every [system gate](../SYSTEMS.md#acceptance-gates), independent safety reviews where required, and an explicit release decision.

Finding closure must record the correcting revision, reproduction-before/fix-after evidence, affected builds, fault tests, physical measurements where needed, remaining limits and reviewer approval. A documentation edit or passing compile alone cannot close a firmware/hardware finding.

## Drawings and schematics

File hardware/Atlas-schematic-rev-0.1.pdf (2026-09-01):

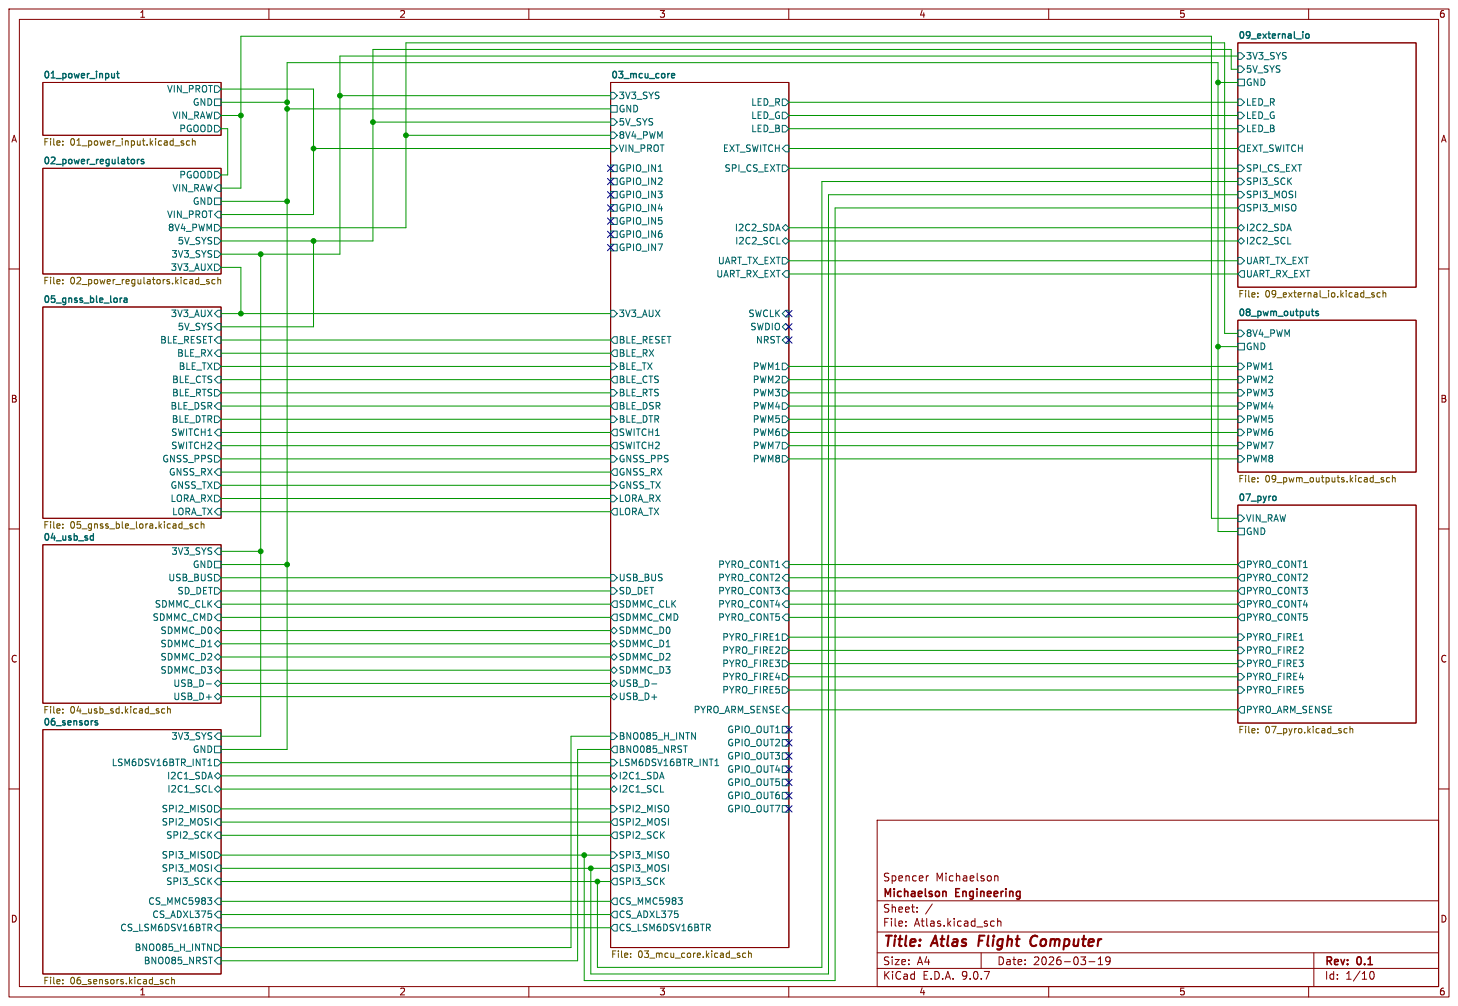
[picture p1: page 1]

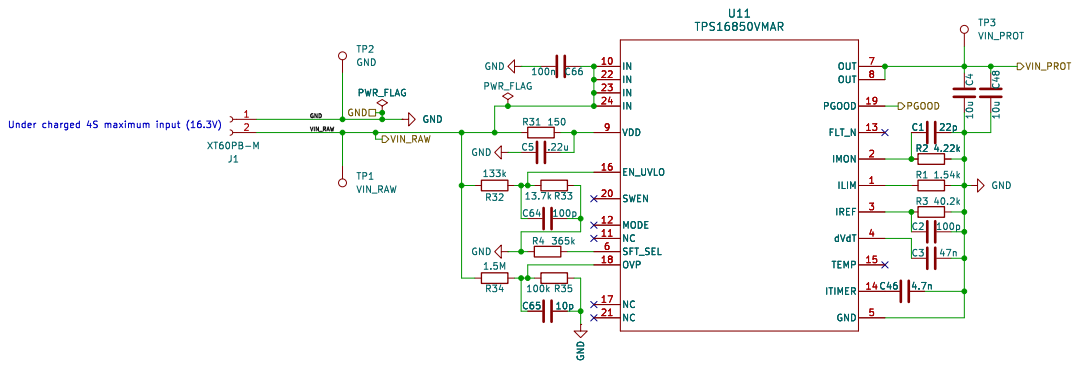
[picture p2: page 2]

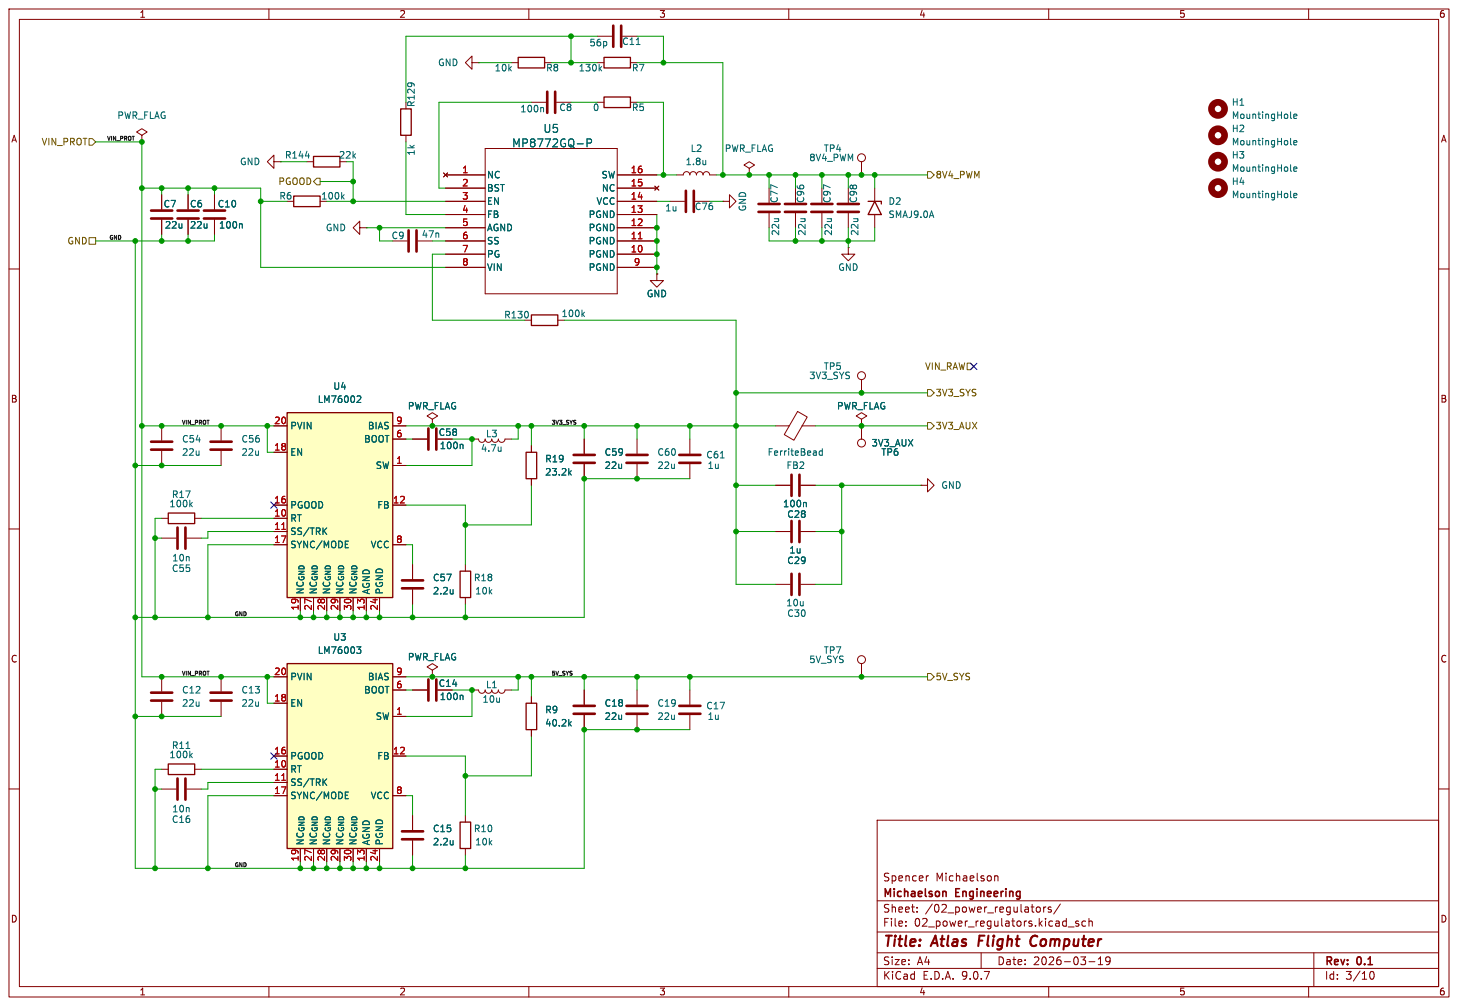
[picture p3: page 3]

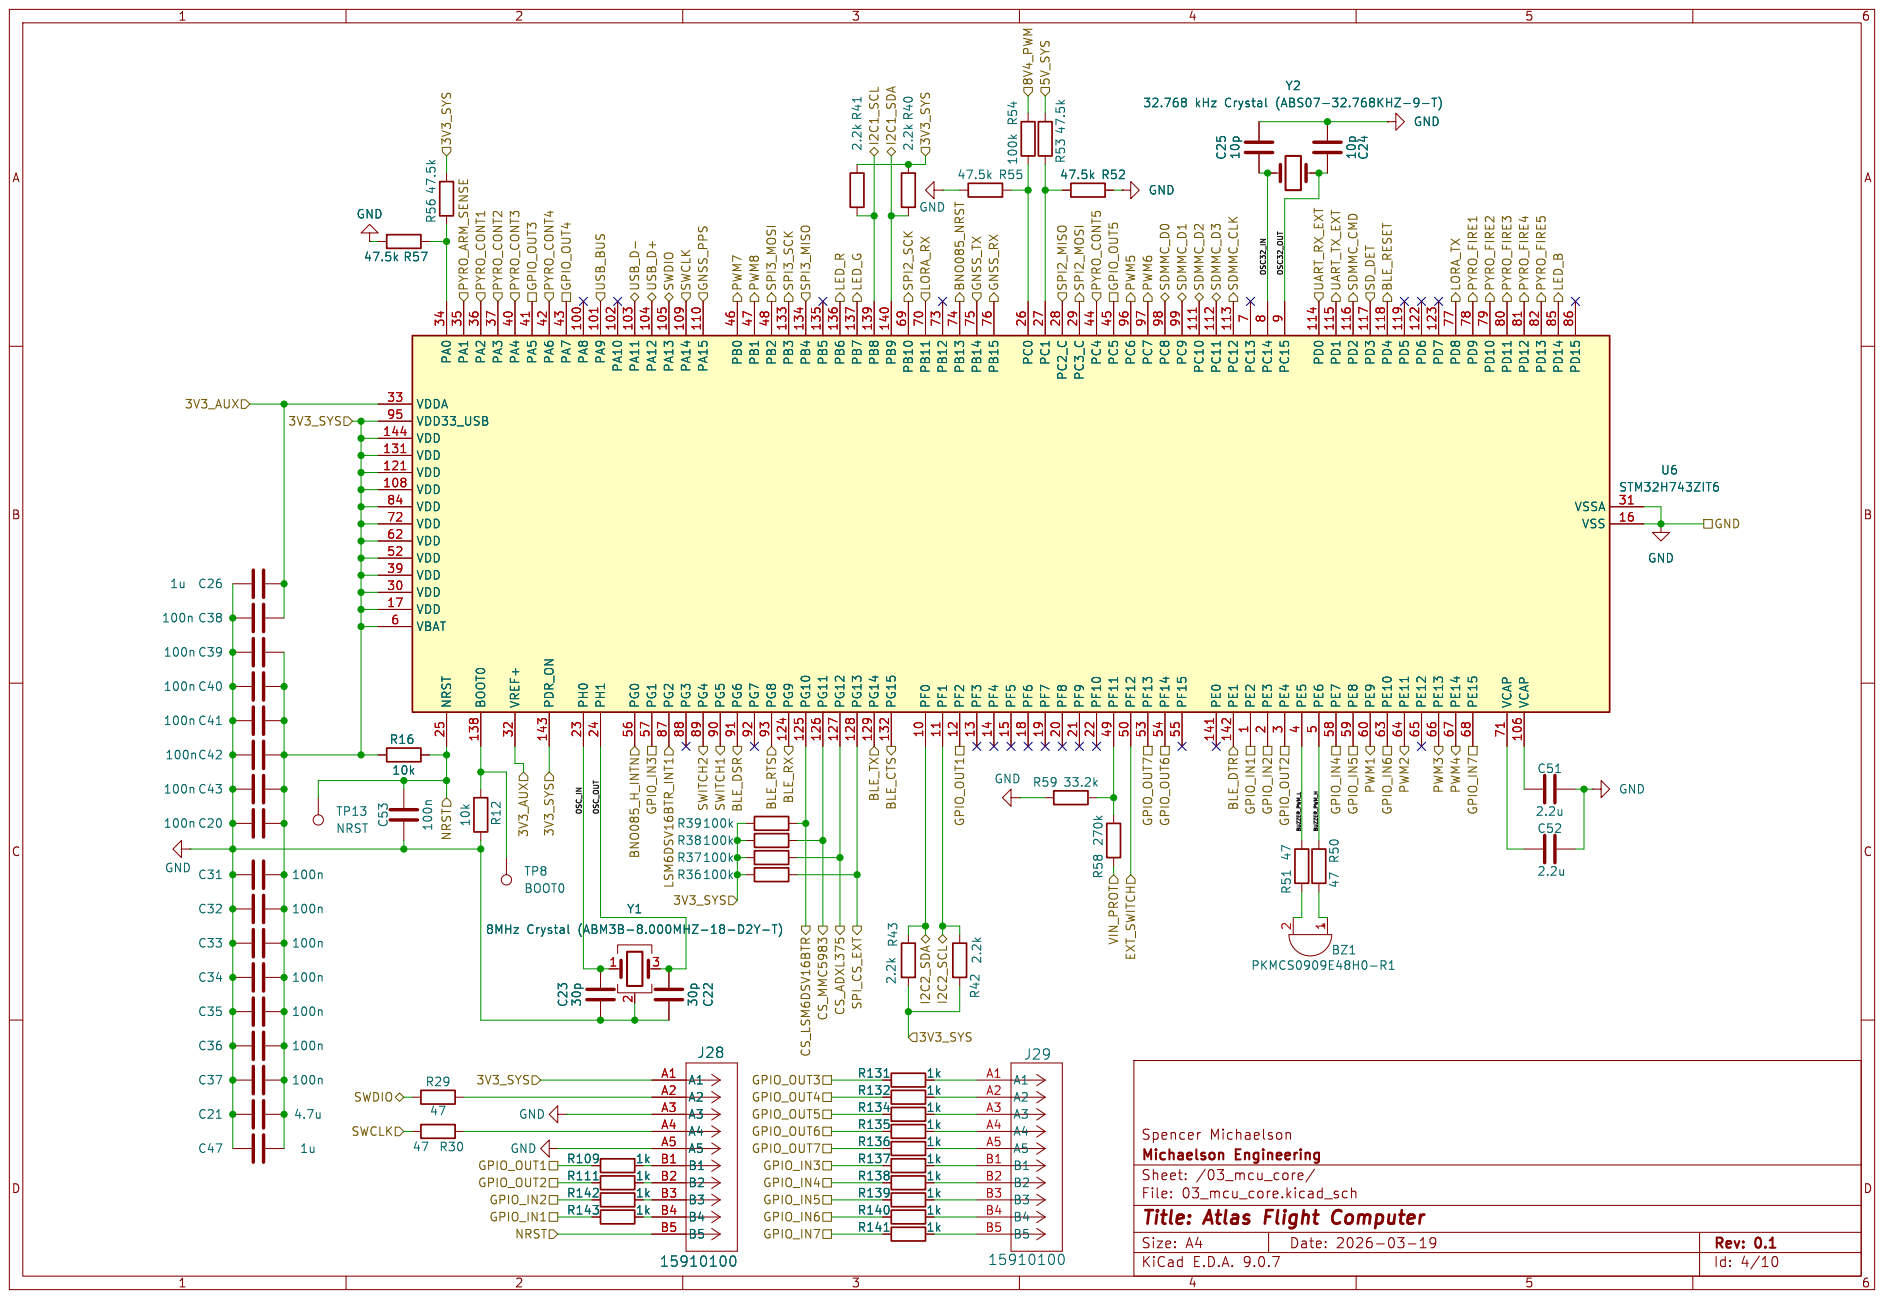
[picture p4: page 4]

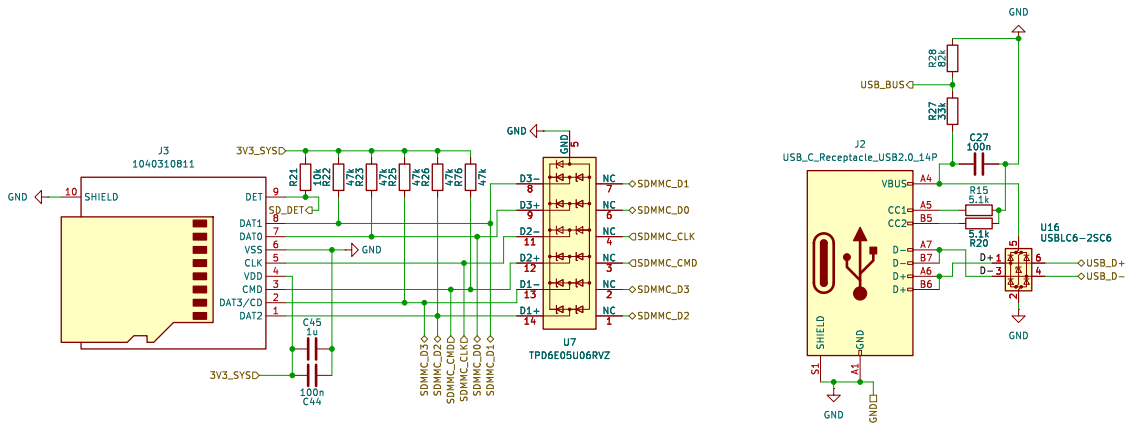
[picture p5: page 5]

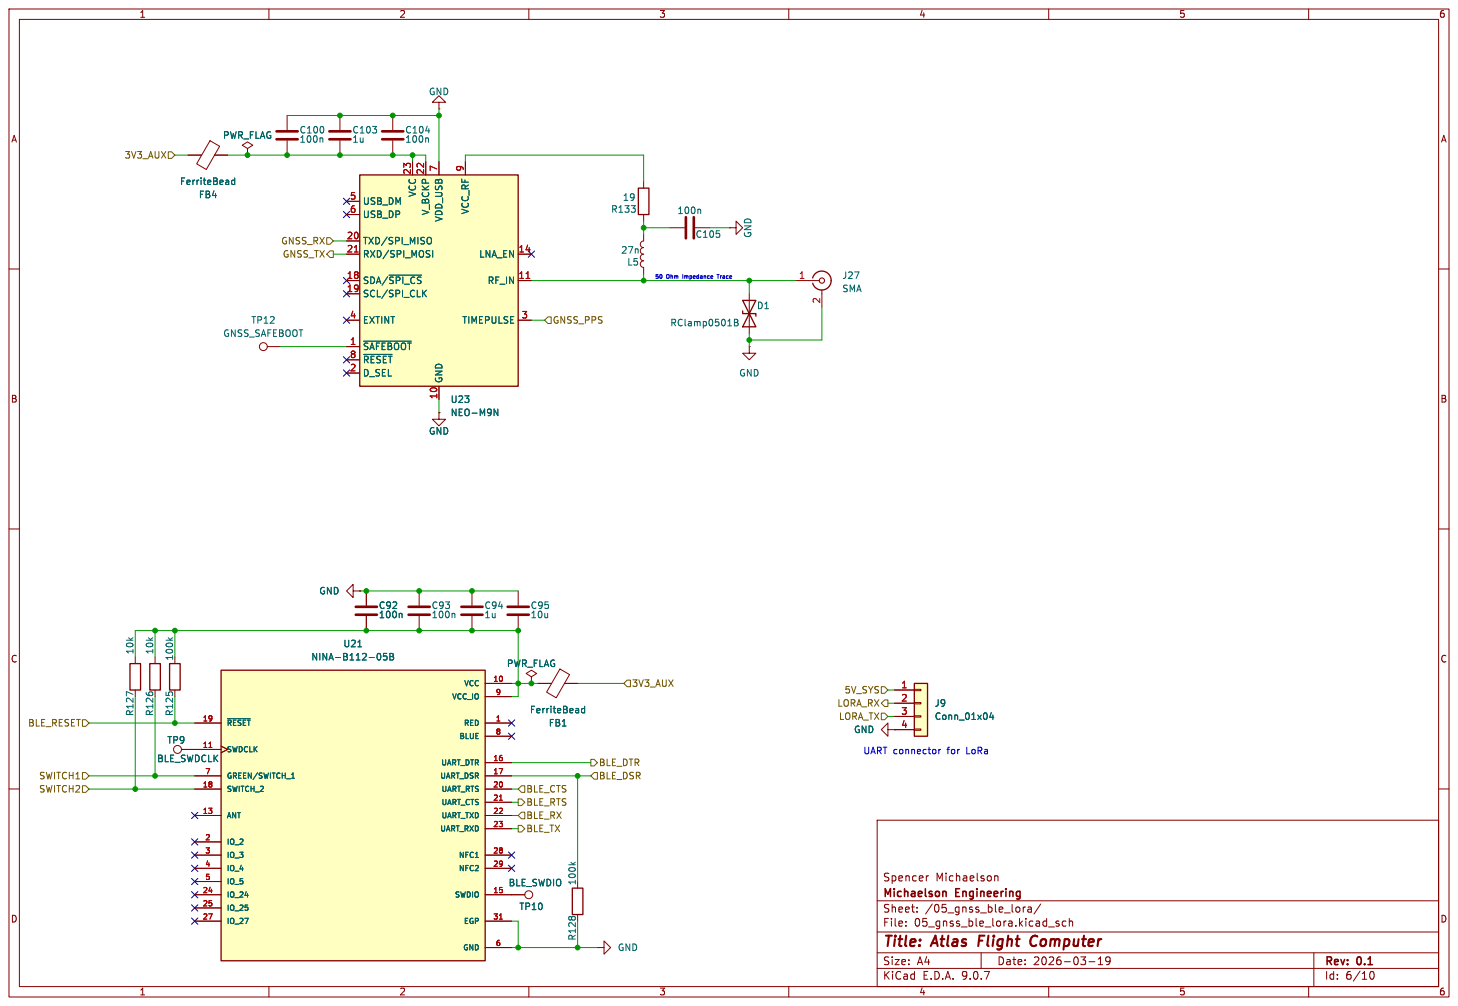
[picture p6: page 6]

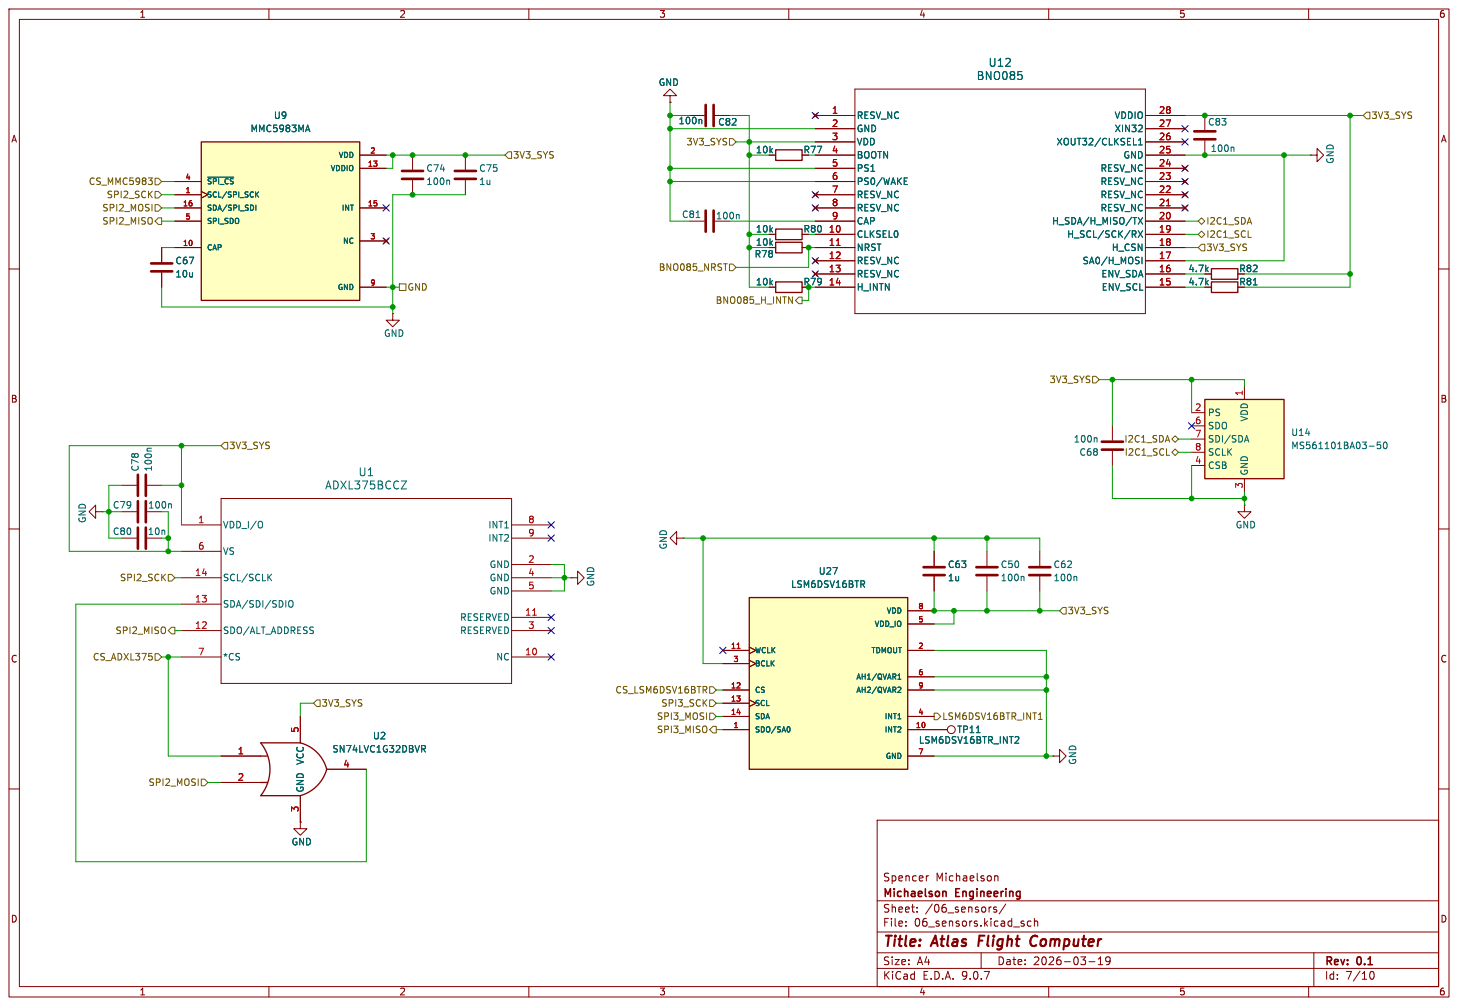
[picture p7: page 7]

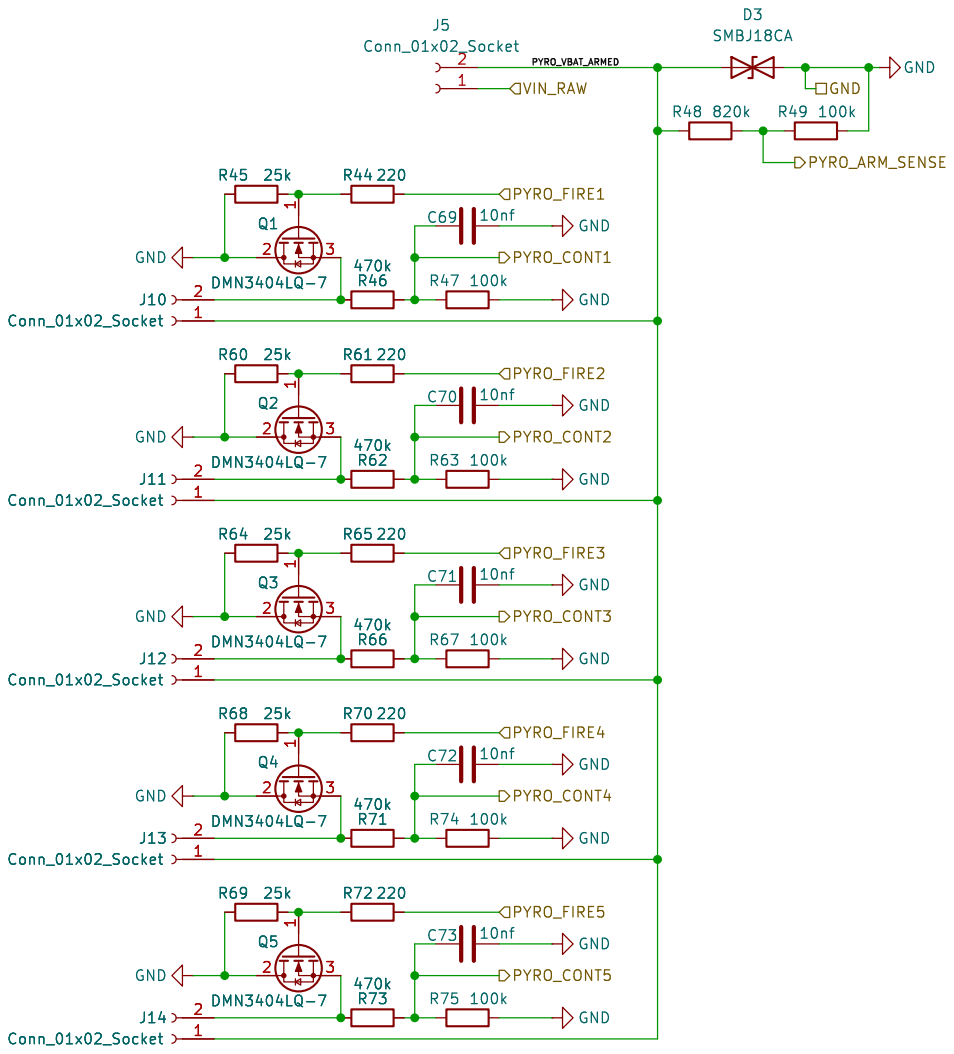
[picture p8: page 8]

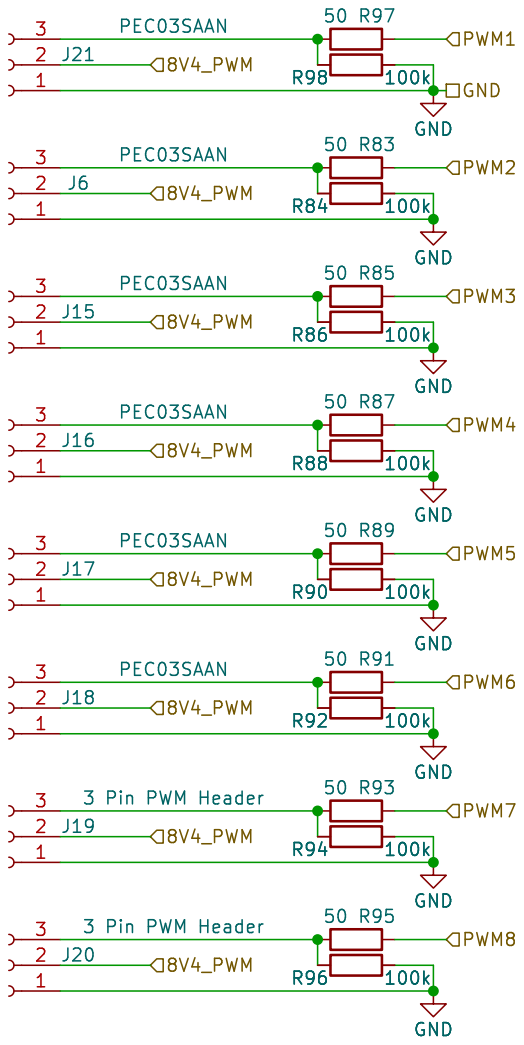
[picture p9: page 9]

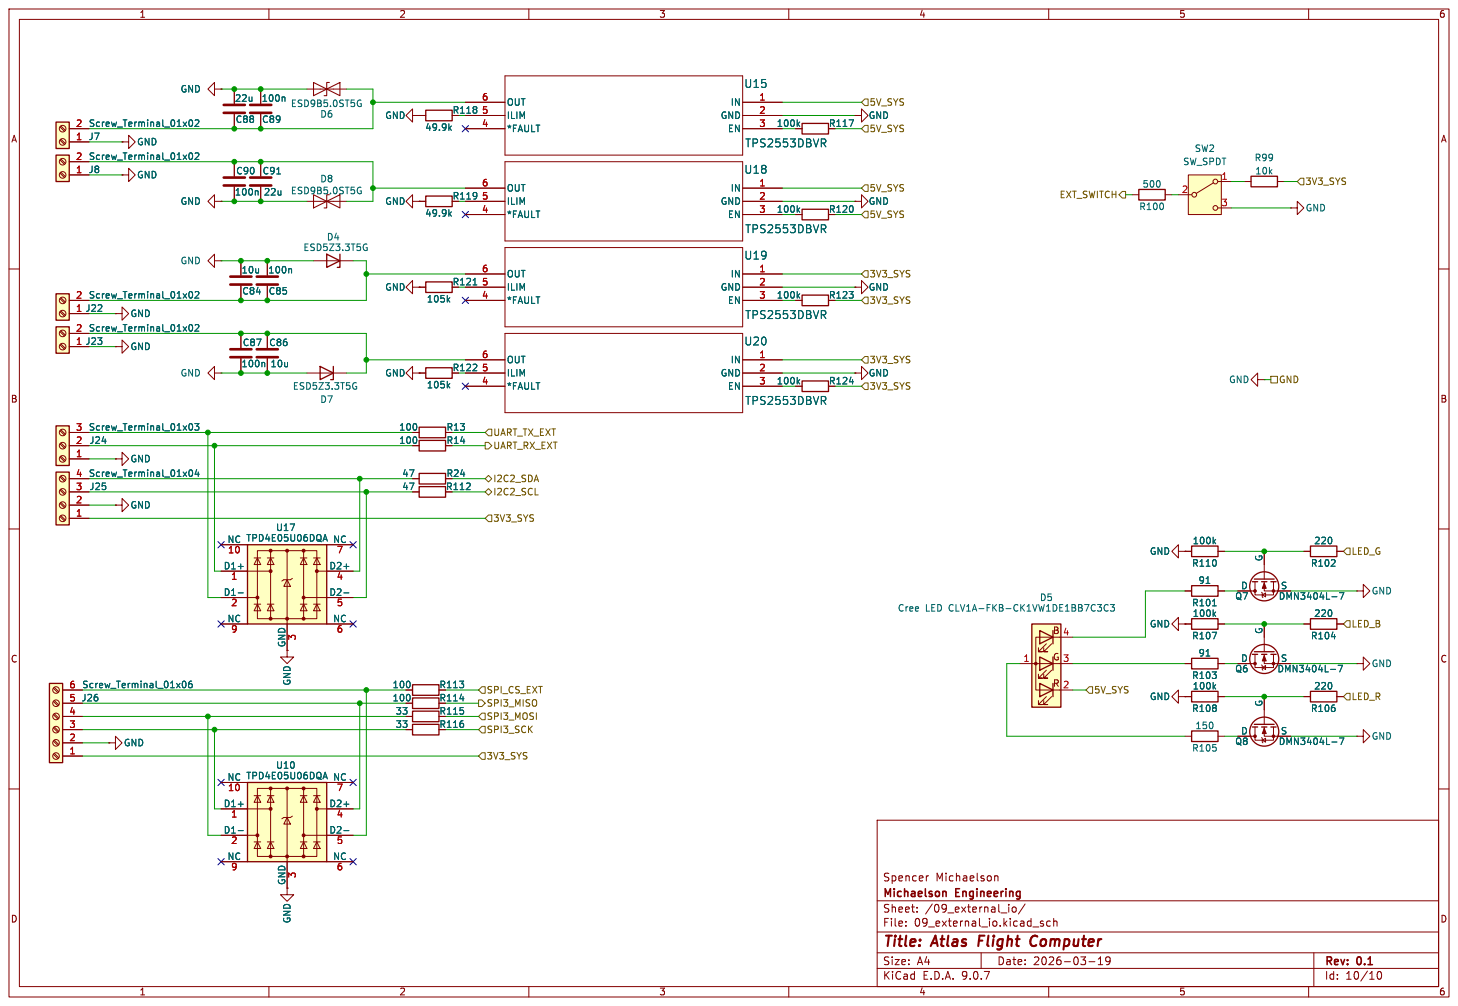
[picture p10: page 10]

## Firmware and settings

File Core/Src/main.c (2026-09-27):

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
/* Includes ------------------------------------------------------------------*/
#include "main.h"
#include "fatfs.h"

/* USER CODE BEGIN Includes */
#include "atlas_board.h"
#include "atlas_rtos.h"
#include "atlas_build.h"
#include "atlas_bringup.h"
#include "atlas_boot.h"
/* USER CODE END Includes */

ADC_HandleTypeDef hadc1;
ADC_HandleTypeDef hadc3;
DMA_HandleTypeDef hdma_adc1;

I2C_HandleTypeDef hi2c1;
I2C_HandleTypeDef hi2c2;

IWDG_HandleTypeDef hiwdg1;

RAMECC_HandleTypeDef hramecc1_m1;
RAMECC_HandleTypeDef hramecc1_m4;
RAMECC_HandleTypeDef hramecc2_m1;
RAMECC_HandleTypeDef hramecc3_m1;

RTC_HandleTypeDef hrtc;

SD_HandleTypeDef hsd1;

SPI_HandleTypeDef hspi2;
SPI_HandleTypeDef hspi3;

TIM_HandleTypeDef htim1;
TIM_HandleTypeDef htim2;
TIM_HandleTypeDef htim3;
TIM_HandleTypeDef htim4;
TIM_HandleTypeDef htim5;
TIM_HandleTypeDef htim6;
TIM_HandleTypeDef htim15;
DMA_HandleTypeDef hdma_tim6_up;

UART_HandleTypeDef huart4;
UART_HandleTypeDef huart1;
UART_HandleTypeDef huart3;
UART_HandleTypeDef huart6;

/* USER CODE BEGIN PV */
static AtlasBoard atlas_board;
static volatile AtlasStatus atlas_board_startup_status;
static volatile AtlasStatus atlas_rtos_start_status;
/* USER CODE END PV */

void SystemClock_Config(void);
void PeriphCommonClock_Config(void);
static void MPU_Config(void);
static void MX_GPIO_Init(void);
static void MX_DMA_Init(void);
static void MX_ADC1_Init(void);
static void MX_I2C1_Init(void);
static void MX_I2C2_Init(void);
static void MX_SDMMC1_SD_Init(void);
static void MX_SPI2_Init(void);
static void MX_SPI3_Init(void);
static void MX_TIM1_Init(void);
static void MX_TIM2_Init(void);
static void MX_TIM3_Init(void);
static void MX_TIM4_Init(void);
static void MX_TIM5_Init(void);
static void MX_TIM15_Init(void);
static void MX_UART4_Init(void);
static void MX_USART1_UART_Init(void);
static void MX_USART3_UART_Init(void);
static void MX_USART6_UART_Init(void);
static void MX_ADC3_Init(void);
static void MX_IWDG1_Init(void);
static void MX_RAMECC_Init(void);
static void MX_RTC_Init(void);
static void MX_TIM6_Init(void);
/* USER CODE BEGIN PFP */
#if defined(__GNUC__)
/* FatFs initializes SDMMC lazily through BSP_SD_Init(); CubeMX still emits this helper. */
static void MX_SDMMC1_SD_Init(void) __attribute__((unused));
#endif
/* USER CODE END PFP */

/**
  * @brief  The application entry point.
  * @retval int
  */
int main(void)
{

  /* USER CODE BEGIN 1 */
  AtlasBoot_EarlyCheck();
  /* USER CODE END 1 */

  /* MPU Configuration--------------------------------------------------------*/
  MPU_Config();

  /* Enable the CPU Cache */

  /* Enable I-Cache---------------------------------------------------------*/
  SCB_EnableICache();

  /* MCU Configuration--------------------------------------------------------*/

  /* Reset of all peripherals, Initializes the Flash interface and the Systick. */
  HAL_Init();

  /* Configure the system clock */
  SystemClock_Config();

  /* Configure the peripherals common clocks */
  PeriphCommonClock_Config();

  /* Initialize all configured peripherals */
  MX_GPIO_Init();
  MX_DMA_Init();
  MX_ADC1_Init();
  MX_I2C1_Init();
  MX_I2C2_Init();
  MX_SPI2_Init();
  MX_SPI3_Init();
  MX_TIM1_Init();
  MX_TIM2_Init();
  MX_TIM3_Init();
  MX_TIM4_Init();
  MX_TIM5_Init();
  MX_TIM15_Init();
  MX_UART4_Init();
  MX_USART1_UART_Init();
  MX_USART3_UART_Init();
  MX_USART6_UART_Init();
  MX_ADC3_Init();
  MX_RAMECC_Init();
  MX_RTC_Init();
  MX_TIM6_Init();
  MX_FATFS_Init();
  /* USER CODE BEGIN 2 */
  {
    const AtlasBoardHardware hardware = {
      .sensor_i2c = &hi2c1,
      .shared_sensor_spi = &hspi2,
      .imu_spi = &hspi3,
      .gnss_uart = &huart1,
      .radio_uart = &huart3,
      .ble_uart = &huart6,
      .expansion_uart = &huart4,
      .expansion_i2c = &hi2c2,
      .microsecond_pps_timer = &htim2,
      .buzzer_timer = &htim15,
      .rtc = &hrtc,
      .io = {
        .adc_external = &hadc1, .adc_internal = &hadc3,
        .pwm_1_to_4 = &htim1, .pwm_5_to_8 = &htim3,
        .pyro_timer = &htim6, .pyro_dma = &hdma_tim6_up
      }
    };
    atlas_board_startup_status = AtlasBoard_Init(&atlas_board, &hardware);
  }

  /* Start the watchdog only after bounded module probes that can take several seconds. */
  MX_IWDG1_Init();
#if ATLAS_BRINGUP
  /* Diagnostic tasks reuse the same peripheral owners, but never the flight hook. */
  atlas_rtos_start_status = AtlasBringup_Start(&atlas_board, &hiwdg1);
#else
  atlas_rtos_start_status = AtlasRtos_Start(&atlas_board,
                                             &hiwdg1,
                                             atlas_board_startup_status);
#endif
  /* A healthy scheduler never returns. Preserve the failure for a debugger. */
  (void)atlas_rtos_start_status;
  Error_Handler();
  /* USER CODE END 2 */

  /* Infinite loop */
  /* USER CODE BEGIN WHILE */
  while (1)
  {
    /* USER CODE END WHILE */

    /* USER CODE BEGIN 3 */
    /* Unreachable unless Error_Handler() is replaced during a debug experiment. */
    __WFI();
  }
  /* USER CODE END 3 */
}

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
 /* MPU Configuration */

void MPU_Config(void)
{
  MPU_Region_InitTypeDef MPU_InitStruct = {0};

  /* Disables the MPU */
  HAL_MPU_Disable();

  /** Initializes and configures the Region and the memory to be protected
  */
  MPU_InitStruct.Enable = MPU_REGION_ENABLE;
  MPU_InitStruct.Number = MPU_REGION_NUMBER0;
  MPU_InitStruct.BaseAddress = 0x0;
  MPU_InitStruct.Size = MPU_REGION_SIZE_4GB;
  MPU_InitStruct.SubRegionDisable = 0x87;
  MPU_InitStruct.TypeExtField = MPU_TEX_LEVEL0;
  MPU_InitStruct.AccessPermission = MPU_REGION_NO_ACCESS;
  MPU_InitStruct.DisableExec = MPU_INSTRUCTION_ACCESS_DISABLE;
  MPU_InitStruct.IsShareable = MPU_ACCESS_SHAREABLE;
  MPU_InitStruct.IsCacheable = MPU_ACCESS_NOT_CACHEABLE;
  MPU_InitStruct.IsBufferable = MPU_ACCESS_NOT_BUFFERABLE;

  HAL_MPU_ConfigRegion(&MPU_InitStruct);

  /** Initializes and configures the Region and the memory to be protected
  */
  MPU_InitStruct.Number = MPU_REGION_NUMBER1;
  MPU_InitStruct.BaseAddress = 0x2001BF00;
  MPU_InitStruct.Size = MPU_REGION_SIZE_256B;
  MPU_InitStruct.SubRegionDisable = 0x0;
  MPU_InitStruct.IsShareable = MPU_ACCESS_NOT_SHAREABLE;

  HAL_MPU_ConfigRegion(&MPU_InitStruct);
  /* Enables the MPU */
  HAL_MPU_Enable(MPU_PRIVILEGED_DEFAULT);

}

/**
  * @brief  This function is executed in case of error occurrence.
  * @retval None
  */
void Error_Handler(void)
{
  /* USER CODE BEGIN Error_Handler_Debug */
  /* User can add his own implementation to report the HAL error return state */
  AtlasRtos_InhibitOutputs();
  __disable_irq();
  while (1)
  {
  }
  /* USER CODE END Error_Handler_Debug */
}
#ifdef USE_FULL_ASSERT
/**
  * @brief  Reports the name of the source file and the source line number
  *         where the assert_param error has occurred.
  * @param  file: pointer to the source file name
  * @param  line: assert_param error line source number
  * @retval None
  */
void assert_failed(uint8_t *file, uint32_t line)
{
  /* USER CODE BEGIN 6 */
  /* User can add his own implementation to report the file name and line number,
     ex: printf("Wrong parameters value: file %s on line %d\r\n", file, line) */
  /* USER CODE END 6 */
}
#endif /* USE_FULL_ASSERT */

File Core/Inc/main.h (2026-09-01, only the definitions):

#define GPIO_IN1_Pin GPIO_PIN_2
#define GPIO_IN1_GPIO_Port GPIOE
#define GPIO_IN2_Pin GPIO_PIN_3
#define GPIO_IN2_GPIO_Port GPIOE
#define GPIO_OUT2_Pin GPIO_PIN_4
#define GPIO_OUT2_GPIO_Port GPIOE
#define BUZZER_PWM_L_Pin GPIO_PIN_5
#define BUZZER_PWM_L_GPIO_Port GPIOE
#define BUZZER_PWM_H_Pin GPIO_PIN_6
#define BUZZER_PWM_H_GPIO_Port GPIOE
#define GPIO_OUT1_Pin GPIO_PIN_2
#define GPIO_OUT1_GPIO_Port GPIOF
#define SENSE_8V4_Pin GPIO_PIN_0
#define SENSE_8V4_GPIO_Port GPIOC
#define SENSE_5V_SYS_Pin GPIO_PIN_1
#define SENSE_5V_SYS_GPIO_Port GPIOC
#define SENSE_3V3_SYS_Pin GPIO_PIN_0
#define SENSE_3V3_SYS_GPIO_Port GPIOA
#define PYRO_ARMED_SENSE_Pin GPIO_PIN_1
#define PYRO_ARMED_SENSE_GPIO_Port GPIOA
#define PYRO_CONT1_Pin GPIO_PIN_2
#define PYRO_CONT1_GPIO_Port GPIOA
#define PYRO_CONT2_Pin GPIO_PIN_3
#define PYRO_CONT2_GPIO_Port GPIOA
#define PYRO_CONT3_Pin GPIO_PIN_4
#define PYRO_CONT3_GPIO_Port GPIOA
#define GPIO_OUT3_Pin GPIO_PIN_5
#define GPIO_OUT3_GPIO_Port GPIOA
#define PYRO_CONT4_Pin GPIO_PIN_6
#define PYRO_CONT4_GPIO_Port GPIOA
#define GPIO_OUT4_Pin GPIO_PIN_7
#define GPIO_OUT4_GPIO_Port GPIOA
#define PYRO_CONT5_Pin GPIO_PIN_4
#define PYRO_CONT5_GPIO_Port GPIOC
#define GPIO_OUT5_Pin GPIO_PIN_5
#define GPIO_OUT5_GPIO_Port GPIOC
#define PWM7_Pin GPIO_PIN_0
#define PWM7_GPIO_Port GPIOB
#define PWM8_Pin GPIO_PIN_1
#define PWM8_GPIO_Port GPIOB
#define SENSE_VIN_PROT_Pin GPIO_PIN_11
#define SENSE_VIN_PROT_GPIO_Port GPIOF
#define EXT_SWITCH_Pin GPIO_PIN_12
#define EXT_SWITCH_GPIO_Port GPIOF
#define EXT_SWITCH_EXTI_IRQn EXTI15_10_IRQn
#define GPIO_OUT7_Pin GPIO_PIN_13
#define GPIO_OUT7_GPIO_Port GPIOF
#define GPIO_OUT6_Pin GPIO_PIN_14
#define GPIO_OUT6_GPIO_Port GPIOF
#define BNO085_H_INTN_Pin GPIO_PIN_0
#define BNO085_H_INTN_GPIO_Port GPIOG
#define BNO085_H_INTN_EXTI_IRQn EXTI0_IRQn
#define GPIO_IN3_Pin GPIO_PIN_1
#define GPIO_IN3_GPIO_Port GPIOG
#define GPIO_IN4_Pin GPIO_PIN_7
#define GPIO_IN4_GPIO_Port GPIOE
#define GPIO_IN5_Pin GPIO_PIN_8
#define GPIO_IN5_GPIO_Port GPIOE
#define PWM1_Pin GPIO_PIN_9
#define PWM1_GPIO_Port GPIOE
#define GPIO_IN6_Pin GPIO_PIN_10
#define GPIO_IN6_GPIO_Port GPIOE
#define PWM2_Pin GPIO_PIN_11
#define PWM2_GPIO_Port GPIOE
#define PWM3_Pin GPIO_PIN_13
#define PWM3_GPIO_Port GPIOE
#define PWM4_Pin GPIO_PIN_14
#define PWM4_GPIO_Port GPIOE
#define GPIO_IN7_Pin GPIO_PIN_15
#define GPIO_IN7_GPIO_Port GPIOE
#define LORA_RX_Pin GPIO_PIN_11
#define LORA_RX_GPIO_Port GPIOB
#define BNO085_NRST_Pin GPIO_PIN_13
#define BNO085_NRST_GPIO_Port GPIOB
#define GNSS_TX_Pin GPIO_PIN_14
#define GNSS_TX_GPIO_Port GPIOB
#define GNSS_RX_Pin GPIO_PIN_15
#define GNSS_RX_GPIO_Port GPIOB
#define LORA_TX_Pin GPIO_PIN_8
#define LORA_TX_GPIO_Port GPIOD
#define PYRO_FIRE1_Pin GPIO_PIN_9
#define PYRO_FIRE1_GPIO_Port GPIOD
#define PYRO_FIRE2_Pin GPIO_PIN_10
#define PYRO_FIRE2_GPIO_Port GPIOD
#define PYRO_FIRE3_Pin GPIO_PIN_11
#define PYRO_FIRE3_GPIO_Port GPIOD
#define PYRO_FIRE4_Pin GPIO_PIN_12
#define PYRO_FIRE4_GPIO_Port GPIOD
#define PYRO_FIRE5_Pin GPIO_PIN_13
#define PYRO_FIRE5_GPIO_Port GPIOD
#define LED_B_Pin GPIO_PIN_14
#define LED_B_GPIO_Port GPIOD
#define LSM6_INT1_Pin GPIO_PIN_2
#define LSM6_INT1_GPIO_Port GPIOG
#define LSM6_INT1_EXTI_IRQn EXTI2_IRQn
#define BLE_SWITCH2_Pin GPIO_PIN_4
#define BLE_SWITCH2_GPIO_Port GPIOG
#define BLE_SWITCH1_Pin GPIO_PIN_5
#define BLE_SWITCH1_GPIO_Port GPIOG
#define BLE_DSR_Pin GPIO_PIN_6
#define BLE_DSR_GPIO_Port GPIOG
#define BLE_RTS_Pin GPIO_PIN_8
#define BLE_RTS_GPIO_Port GPIOG
#define PWM5_Pin GPIO_PIN_6
#define PWM5_GPIO_Port GPIOC
#define PWM6_Pin GPIO_PIN_7
#define PWM6_GPIO_Port GPIOC
#define USB_VBUS_Pin GPIO_PIN_9
#define USB_VBUS_GPIO_Port GPIOA
#define USB_VBUS_EXTI_IRQn EXTI9_5_IRQn
#define GNSS_PPS_Pin GPIO_PIN_15
#define GNSS_PPS_GPIO_Port GPIOA
#define EXT1_RX_Pin GPIO_PIN_0
#define EXT1_RX_GPIO_Port GPIOD
#define EXT1_TX_Pin GPIO_PIN_1
#define EXT1_TX_GPIO_Port GPIOD
#define SD_DET_Pin GPIO_PIN_3
#define SD_DET_GPIO_Port GPIOD
#define SD_DET_EXTI_IRQn EXTI3_IRQn
#define BLE_RESET_N_Pin GPIO_PIN_4
#define BLE_RESET_N_GPIO_Port GPIOD
#define BLE_RX_Pin GPIO_PIN_9
#define BLE_RX_GPIO_Port GPIOG
#define CS_LSM6DSV16B_Pin GPIO_PIN_10
#define CS_LSM6DSV16B_GPIO_Port GPIOG
#define CS_MMC5983_Pin GPIO_PIN_11
#define CS_MMC5983_GPIO_Port GPIOG
#define CS_ADXL375_Pin GPIO_PIN_12
#define CS_ADXL375_GPIO_Port GPIOG
#define CS_SPI_EXT_Pin GPIO_PIN_13
#define CS_SPI_EXT_GPIO_Port GPIOG
#define BLE_TX_Pin GPIO_PIN_14
#define BLE_TX_GPIO_Port GPIOG
#define BLE_CTS_Pin GPIO_PIN_15
#define BLE_CTS_GPIO_Port GPIOG
#define LED_R_Pin GPIO_PIN_6
#define LED_R_GPIO_Port GPIOB
#define LED_G_Pin GPIO_PIN_7
#define LED_G_GPIO_Port GPIOB
#define BLE_DTR_Pin GPIO_PIN_1
#define BLE_DTR_GPIO_Port GPIOE
#define BLE_DTR_EXTI_IRQn EXTI1_IRQn

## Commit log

2026-09-01 Initial documentation added
    [Atlas-B_Cu.gbr, Atlas-B_Mask.gbr, Atlas-B_Paste.gbr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]
2026-09-04 Changed GNSS startup behavior and disabled LED
2026-09-11 Added Servo Control
2026-09-26 Added active stability demonstrator
    [atlas_bringup.c, atlas_bringup_protocol.c, atlas_io.c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]

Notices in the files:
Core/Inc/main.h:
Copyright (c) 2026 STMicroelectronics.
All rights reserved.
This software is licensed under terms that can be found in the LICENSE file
